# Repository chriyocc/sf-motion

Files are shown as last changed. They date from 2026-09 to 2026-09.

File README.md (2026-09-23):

# SF-Motion

**Open-source BLDC/PMSM motor control platform based on STM32 and Field-Oriented Control (FOC).**

The project includes:

- FOC firmware
- Custom motor driver hardware
- KiCad schematic and PCB design
- Gerber and BOM files
- Python communication and control tools
- PyQt/PyQtGraph GUI for motor monitoring and testing

> ⚠️ This project is under active development. Hardware and firmware may change between versions.

## My Tips
For everyday operation, calibration, control modes, plotting, and troubleshooting, see the [complete motor user guide](MOTOR_USER_GUIDE.md).

To start virtual env
`Set-ExecutionPolicy -Scope Process -ExecutionPolicy Bypass`
`.venv\Scripts\Activate.ps1`

To start GUI
`python communication/motor.py`

## Hardware Prerequisites

You will need:
- FOC Driver Board
- ST-Link programmer/debugger with 3-pin Molex pico-blade P1.25mm connector
- DC power supply
- BLDC/PMSM motor
- diametrical magnet
- USB type-C cable
- power cable with XT-30 female connector

The hardware design is available in:
```
Hardware/
├── production/        # Gerber manufacturing files
├── .kicad_sch         # Schematic
├── .kicad_pcb         # PCB design
└── ...
```

## Software Prerequisites

### 1. STM32CubeMX

Used to configure the STM32 peripherals and generate the initial project configuration.

Download: https://www.st.com/en/development-tools/stm32cubemx.html

### 2. Visual Studio Code

Used as the main development environment.

Download: https://code.visualstudio.com/

### 3. PlatformIO

PlatformIO is used to build and upload the firmware.

Install PlatformIO through the VS Code extension:
1. Open VS Code.
2. Open Extensions.
3. Search for PlatformIO IDE.
4. Install the extension.
5. Restart VS Code if required.

Verify the installation:
``` bash
pio --version
```

If `pio` is not recognized in the terminal, use the PlatformIO terminal inside VS Code or add the PlatformIO CLI directory to your system PATH.

### 4. Python

Python is required for the communication tools and GUI.

Recommended version:
```text
Python 3.10+
```

Download: https://www.python.org/downloads/

Check the installation:
``` bash
python --version
```

Create a virtual environment (recommended):
``` bash
python -m venv .venv
```

Activate it on Windows:
``` bash
.venv\Scripts\activate
```

Activate it on Linux/macOS:
``` bash
source .venv/bin/activate
```

Install the required packages:
``` bash
pip install numpy pyserial PyQt5 pyqtgraph keyboard
```

## Getting Started

Clone the repository using Git:
``` bash
git clone https://github.com/sirojudinMunir/sf-motion.git
```

Enter the project directory:
``` bash
cd SF-Motion
```

## Building the Firmware

Open the project in VS Code with PlatformIO installed.

Build the firmware:
``` bash
pio run
```

If the build is successful, the firmware binary will be generated by PlatformIO.

## Upload Firmware

Connect the ST-Link to the FOC Driver board using the 3-pin PicoBlade connector.

The board can be powered from a **6–24 V external power supply**. For the initial test, it is recommended to use **USB Type-C** as the power source if applicable.

Upload the firmware:
``` bash
pio run -t upload
```

You can also use the Upload button in the PlatformIO interface in VS Code.

## For the first test

After uploading the firmware, follow these steps:

1. Make sure the D3 LED is blinking after the firmware starts.
2. Connect the BLDC/PMSM motor wires to the FOC Driver board. Make sure the diametrical magnet is securely mounted on the motor shaft and properly aligned with the magnetic encoder on the FOC Driver board. The board should be positioned directly beneath the magnet.
3. If you are using an external power supply, set the current limit to 1 A for the initial test. This helps prevent damage if there is an unexpected issue with the board or motor.
4. Connect the USB Type-C cable to the board.
5. Run the Python motor control program:
    ```python
    python communication/motor.py
    ```
6. Select the correct COM port and click Connect.

7. Before running the motor, set the correct motor pole pairs:
    ``` python
    motor.set_pole_pairs(<your_motor_pole_pairs>)
    ```
    Replace <your_motor_pole_pairs> with the actual number of pole pairs of your motor.
8. Run the self-commissioning process:
    ``` python
    motor.self_commissioning()
    ```
    The self-commissioning process measures the motor resistance and inductance and calibrates the magnetic encoder.
    >Important: During encoder calibration, make sure the motor rotates counter-clockwise (CCW). If the motor rotates in the opposite direction, swap any two motor wires to reverse the rotation.
    Automatic motor direction detection will be implemented in a future version.
9. Save configuration
    ``` python
    motor.save_config()
    ```
10. Test the FOC motor modes using:
    ``` python
    motor.set_foc_motor_mode(<mode>)
    ```
    Available modes:

    0 -> for current control mode  
    1 -> for speed control mode  
    2 -> for position control mode  
    5 -> for open-loop mode  
    6 -> for disable the motor

> ⚠️ Keep the power supply current limit low during the first test. Do not increase the voltage or current limit until the board, encoder, and motor are confirmed to be working correctly.

---

## Support SF-Motion

If you find this project useful and would like to support its development,
you can become a sponsor:



Your support helps fund hardware development, testing, documentation,
and future improvements to SF-Motion.

## Update Needed
- Implement overcurrent protection (send fault through CAN)
- 

## Updates compared with the earlier version (2026-09-23)

This section records the firmware, custom GUI, and communication fixes made after the PID/control review. The comparison is against the code before those fixes, rather than a tagged release.

### Firmware changes

| Area | Earlier behavior | Updated behavior |
| --- | --- | --- |
| Saved position PID cutoff | Startup replaced the saved derivative filter cutoff with 20 Hz. | Startup preserves the saved cutoff and recalculates its coefficient after setting the sampling period. |
| PI/PID anti-windup | The integral could keep growing when the proportional term, or combined P+D term, already exceeded the output limit. | Integration stops when it would drive the output further into saturation, while allowing the integral to unwind. |
| PID validation and acknowledgements | Negative gains could be ignored while returning success; negative output maxima could invert the bounds. | PID setters reject invalid values and return an error through the communication protocol. Validation includes non-finite values, ordered output bounds, nonnegative gains/deadbands, and positive filter cutoff and sampling period. |
| PID reset | Reset cleared the integral and previous error but retained filtered derivative history. | Reset also clears the filtered derivative history. |
| USB transmit buffer | A new frame could overwrite bytes still being used by an outstanding USB transfer. | CDC checks availability, then copies the frame into its own transmit buffer before starting the transfer. Oversized frames are rejected. |

### Custom GUI and Python communication changes

These control changes apply to `communication/plotter_custom.py`; the shared protocol changes are in `communication/SFMotionCom.py` and `communication/MotorProtocol.py`.

| Area | Earlier behavior | Updated behavior |
| --- | --- | --- |
| Disable command | A timeout while sending a zero current/speed setpoint could prevent the disable command from being sent. | The GUI attempts disable even when the preliminary zero fails. An unconfirmed disable is reported as unconfirmed. |
| Relative position moves | Targets used the last plotted angle, which became stale when plotting was paused. | The GUI reads the angle directly from the board before calculating a relative target. A failed or non-finite read cancels the move. The position demo also reads its starting angle directly. |
| Reconnect and Apply All | Previously loaded parameters remained eligible for Apply All after reconnecting. | Reconnect, disconnect, a failed Read All, or a failed Apply All invalidates the loaded-parameter state. A successful Read All is required before Apply All is allowed again. |
| PID input fields | PID fields allowed negative values regardless of their meaning. | Gains, deadbands, and output maxima are nonnegative; derivative cutoff is positive; field-weakening output minimum is nonpositive. The protocol validates all values in a PID group before its first write. |
| Request/reply handling | Requests consumed the next queued reply, allowing delayed replies to disrupt later requests. | Requests are serialized. A timeout, transport failure, or malformed/mismatched reply invalidates the session and requires reconnecting. A disable write remains possible, but is explicitly unconfirmed in that state. |
| Partial parameter updates | Failure during a group write could leave some registers updated without a clear recovery instruction. | Failures explicitly report a possible partial update and instruct the user to reconnect if required, then read parameters before retrying. |
| Connection setup failures | Only serial-specific exceptions were caught during connection setup. | Setup failures also clean up the connection and report the error. |

### Applying the update

- **Firmware changes require a successful flash and verification.** Building alone does not update the board.
- Build the main firmware with `pio run -e genericSTM32F405RG`. The output is `.pio/build/genericSTM32F405RG/firmware.bin`.
- **GUI changes require restarting the Python GUI.** After connecting, use Read All Parameters before Apply All.
- PID register mappings and the on-wire frame format remain unchanged.

### Validation and remaining limitations

- The main firmware build passed.
- All 16 Python GUI/protocol tests passed, including the two existing plotting tests and 14 new regression tests. Serial interactions in these tests are mocked.
- Added C regression tests for PI/PID saturation and unwinding, invalid values, filter initialization, and reset behavior. They were compiled with the ARM toolchain but have not been executed here.
- PID groups still use separate register writes; they are **not atomic**. A connection failure can leave a partial update, and automatic rollback is not attempted.
- Motor behavior and USB transfer behavior have not been verified on hardware. The reported CubeProgrammer erase failure remains unresolved; the updated firmware has not been confirmed installed on the board.
- The VCAP capacitor values discussed during troubleshooting are a hardware check, not a hardware modification included in this update.

See [hardware-free test instructions and communication recovery](tests/README.md) for details.

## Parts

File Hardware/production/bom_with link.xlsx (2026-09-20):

Designator | Footprint | Quantity | Value | LCSC Part # | Link
C1, C10, C11, C2, C21, C3, C31, C37, C4, C40, C41, C45, C47, C48, C49, C5, C50, C51, C7 | 0402 | 19 | 100nF | C1525 | https://item.taobao.com/item.htm?id=619644090710
C12, C16, C17, C25, C26, C27, C28, C29, C30, C32, C33, C34, C35, C38, C39, C43, C44 | 0805 | 17 | 10uF | C22367830 | https://item.taobao.com/item.htm?id=537776958252
C13, C15 | 0603 | 2 | 0.1uF | C1591 | https://item.taobao.com/item.htm?id=537669338432&skuId=5720849848357
C14 | 0805 | 1 | 4.7uF | C98192 | https://item.taobao.com/item.htm?id=522572786930
C18, C20, C22 | 0603 | 3 | 1uF | C5199872 | https://item.taobao.com/item.htm?id=537669338432&skuId=5720849848378
C19 | 0603 | 1 | 47nF | C1622 | https://item.taobao.com/item.htm?id=537669338432&skuId=5720849848289
C23 | 0603 | 1 | 2.2uF | C23630 | https://item.taobao.com/item.htm?id=537669338432&skuId=5720849848299
C24 | 0402 | 1 | 10nF | C15195 | https://item.taobao.com/item.htm?id=523808399191&skuId=5896917567579
C36, C42, C46 | 0402 | 3 | 1nF | C14442 | https://item.taobao.com/item.htm?id=523808399191&skuId=5896917567577
C6 | 0402 | 1 | 1uF | C29266 | https://item.taobao.com/item.htm?id=523832610965
C8, C9 | 0402 | 2 | 33pF | C70465 | https://item.taobao.com/item.htm?id=574673920044&skuId=5723010237031
D1, D2 | 0603 | 2 | LED RED | C19171390 | https://item.taobao.com/item.htm?id=607210300413
D3 | 0603 | 1 | LED GREEN | C2986048 | https://item.taobao.com/item.htm?id=522573309525
D4, D5 | D_SOD-123 | 2 | MBR0530 | C5204746 | https://item.taobao.com/item.htm?id=685355899371
FB1 | 0603 | 1 | fcm 1608-0603 | C19330 | https://item.taobao.com/item.htm?id=522576784852&skuId=5903685374892
J1, J8, J9 | Molex_PicoBlade_53261-0371_1x03-1MP_P1.25mm_Horizontal | 3 | Conn_01x03_MountingPin | C293630 | https://item.taobao.com/item.htm?id=528734911747&skuId=4981522281626
J10 | Molex_PicoBlade_53261-0671_1x06-1MP_P1.25mm_Horizontal | 1 | Conn_01x06_MountingPin | C17393620 | https://item.taobao.com/item.htm?id=528734911747&skuId=4981522281629
J11 | Molex_PicoBlade_53261-0571_1x05-1MP_P1.25mm_Horizontal | 1 | Conn_01x05_MountingPin | C17256390 | https://item.taobao.com/item.htm?id=528734911747&skuId=4981522281628
J2, J3 | AMASS_XT30PW-M_1x02_P2.50mm_Horizontal | 2 | Conn_01x02 | C431092 | https://item.taobao.com/item.htm?id=635227665423&skuId=4544457080562
J4, J5, J6 | SolderWire-0.25sqmm_1x01_D0.65mm_OD2mm | 3 | Conn_01x01
J7 | USB_C_Receptacle_G-Switch_GT-USB-7010ASV | 1 | USB_C_Receptacle_USB2.0_16P | C2927039 | https://item.taobao.com/item.htm?id=573090887123&skuId=5770750381254
L1 | L_SMD_4X4 | 1 | 22uH | C6364792 | https://item.taobao.com/item.htm?id=589062675723
Q1, Q2, Q3, Q4, Q5, Q6 | TDSON-8-1 | 6 | WSD30100DN56 | C2862136 | https://item.taobao.com/item.htm?id=663046959853
R1, R3 | 0402 | 2 | 10k | C60490 | https://item.taobao.com/item.htm?id=523791322923
R10, R11, R7, R8 | 0402 | 4 | R | Use 75k for R8,R11 | https://item.taobao.com/item.htm?id=525634101247
R12, R15, R17, R21, R22, R25 | 0603 | 6 | 10R | C844919 | https://item.taobao.com/item.htm?id=525741229141&skuId=5869898526190
R13, R19, R23 | R_Shunt_Ohmite_LVK20 | 3 | 0.01R | C844898
R14, R2, R20, R24, R32, R33, R34, R4, R5 | 0402 | 9 | 1k | C852624 | https://item.taobao.com/item.htm?id=559832085134&skuId=5881534858898
R16 | 0603 | 1 | 39k | C163424 | https://item.taobao.com/item.htm?id=525898564027
R18 | 0603 | 1 | 2k2 | C125931 | https://item.taobao.com/item.htm?id=525826728150
R26 | 0402 | 1 | 1k8 | C163481 | https://item.taobao.com/item.htm?id=632063701563
R27, R28 | 0402 | 2 | 100R | C705627 | https://item.taobao.com/item.htm?id=559832085134&skuId=5881534858893
R29, R31 | 0402 | 2 | 30R | C852718 | https://item.taobao.com/item.htm?id=631379668328&skuId=5880747587790
R30 | 0603 | 1 | 120R | C125925 | https://item.taobao.com/item.htm?id=525596814299
R35, R36, R37 | 0402 | 3 | 2k | C852711 | https://item.taobao.com/item.htm?id=631736632107&skuId=5878925082880
R6 | 0603 | 1 | 18k | C309650 | https://item.taobao.com/item.htm?id=559889370450
R9 | 0603 | 1 | 3k3 | C144661 | https://item.taobao.com/item.htm?id=525777943950&skuId=5869585235017
TP1, TP2, TP3, TP4, TP5, TP6, TP7 | TestPoint_Pad_D1.0mm | 7 | TestPoint
U1 | LQFP-64_10x10mm_P0.5mm | 1 | STM32F405RGTx | C15742 | https://item.taobao.com/item.htm?id=522577756409
U10 | TSSOP-14_4.4x5mm_P0.65mm | 1 | AS5047D | C2693743 | https://item.taobao.com/item.htm?id=1029683823182
U2 | QFN50P700X700X100-49N | 1 | DRV8323RHRGZR | C543035 | https://item.taobao.com/item.htm?id=973872188161&from=cart&skuId=6093104858737&upStreamPrice=1350
U3 | SOT-23-5 | 1 | LP2985-3.3 | C95414 | https://item.taobao.com/item.htm?id=572237742889
U4, U6, U7 | TSSOP-8_4.4x3mm_P0.65mm | 3 | INA240A1PW | C93965 | https://item.taobao.com/item.htm?id=756730260979
U5 | SOT-23-5 | 1 | LM321 | C5252901 | https://item.taobao.com/item.htm?id=666849623425
U8 | SOT-23-6 | 1 | USBLC6-2SC6 | C2827654 | https://item.taobao.com/item.htm?id=763430084934
U9 | HVSON-8-1EP_3x3mm_P0.65mm_EP1.6x2.4mm | 1 | TJA1051TK-3 | C2875699 | https://item.taobao.com/item.htm?id=736463710815
Y1 | Crystal_SMD_3225-4Pin_3.2x2.5mm | 1 | 12MHz | C9002 | https://item.taobao.com/item.htm?id=534883366755&skuId=5909761239845

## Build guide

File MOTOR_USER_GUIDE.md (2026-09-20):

# SF-Motion Motor and Plotter User Guide

Checked against this workspace's Python API and firmware on 2026-09-20.
This guide assumes the firmware flashed on your board matches this project.
Examples use your 7-pole-pair motor and sensored FOC. Current and speed examples
are small starting commands, not universal safe limits for every motor or load.

## Contents

1. [Everyday quick start](#1-everyday-quick-start)
2. [Launch and connect](#2-launch-and-connect)
3. [First-time commissioning](#3-first-time-commissioning)
4. [Modes and units](#4-modes-and-units)
5. [Current control](#5-current-control)
6. [Speed control](#6-speed-control)
7. [Position control](#7-position-control)
8. [Encoder readings](#8-encoder-readings)
9. [Plot controls](#9-plot-controls)
10. [PID settings](#10-pid-settings)
11. [Save, reopen, and reset](#11-save-reopen-and-reset)
12. [Troubleshooting](#12-troubleshooting)
13. [Complete command reference](#13-complete-command-reference)
14. [HSI clock notes](#14-hsi-clock-notes)
15. [Implementation references](#15-implementation-references)

## 1. Everyday quick start

Use this after successful commissioning and saving the configuration.
Enter Python commands in the app's bottom console, one line at a time.
Do not type the `>>>` prompt. Use normal underscores, without backslashes.

Connect the app, then start from disabled sensored operation:

```python
motor.set_foc_motor_mode(6)
motor.set_foc_mode(0)
motor.get_pole_pairs()
```

Choose ONE control mode:

| Task | Select mode first | Then send target |
| --- | --- | --- |
| Current/torque | `motor.set_foc_motor_mode(0)` | `motor.set_foc_current_set_point(0.05)` |
| Speed | `motor.set_foc_motor_mode(1)` | `motor.set_foc_speed_set_point(50)` |
| Position | `motor.set_foc_motor_mode(2)` | Follow the relative-angle example in section 7 |
| Disable drive | `motor.set_foc_motor_mode(6)` | No target needed |

The firmware ignores a current, speed, or position setpoint when its matching
motor mode is not active. It can still reply with `{'err_code': 0}`.

Before disconnecting or closing the app:

```python
motor.set_foc_motor_mode(6)
```

Disable removes commanded drive; it is not a controlled braking command or a
guarantee that a moving shaft stops instantly. The current app does not send
disable when you close it or disconnect USB. Keep the DC supply cutoff accessible.

## 2. Launch and connect

Run this in PowerShell from the project folder if `.venv` already exists:

```powershell
.\.venv\Scripts\python.exe communication\motor.py
```

For a fresh Python environment, run these once:

```powershell
python -m venv .venv
.\.venv\Scripts\python.exe -m pip install numpy pyserial PyQt5 pyqtgraph keyboard
.\.venv\Scripts\python.exe communication\motor.py
```

1. Connect USB-C with a data-capable cable.
2. Click **Connect**, select the board's COM port, and use the default 115200 baud.
3. Check communication in the app console:

```python
motor.get_foc_motor_mode()
motor.get_foc_mode()
motor.get_pole_pairs()
```

USB communication alone does not establish that the motor power stage is powered.
For motor movement and commissioning, connect the proper DC bus supply and all
three motor phases. Use the voltage appropriate to your board and motor, with a
conservative supply current limit. Secure the motor and leave its shaft clear.
Disconnect power before changing phase wiring.

Response meanings:

| Response | Meaning |
| --- | --- |
| `{'err_code': 0}` | Handler reported success; not proof of motion, valid calibration, or correct mode |
| `{'err_code': 255}` | Firmware's signed `-1` error decoded as unsigned by Python |
| `{'value': 2.5}` | A measured value or setting; units depend on the command |
| `{'mode': 2}` | A mode value; use the correct mode table below |
| Timeout/traceback | Communication did not complete; do not assume the command had no effect |

## 3. First-time commissioning

Do this for a new motor/encoder setup, changed phase wiring or magnet alignment,
lost calibration, or a previous attempt made with disconnected phases.
You do not need to repeat it just because you reopen the app.

### Prepare

Connect the phases, mount the encoder magnet correctly, power the DC bus, and
allow the motor to rotate freely during encoder calibration.

```python
motor.set_foc_motor_mode(6)
motor.set_foc_mode(0)
motor.set_pole_pairs(7)
motor.get_pole_pairs()
```

Seven pole pairs means 14 magnetic poles. Do not use 7 for a different motor
unless that is its actual pole-pair count.

### Run

```python
motor.self_commissioning()
```

This Python helper starts resistance, d-axis inductance, and q-axis inductance
measurements with one-second delays, prints their values, calculates current PI
gains using a 500 Hz bandwidth, and starts encoder calibration.

**The helper returns after starting encoder calibration. It does not wait for
encoder calibration to finish and does not save the configuration.** Allow the
complete calibration movement to finish before changing modes or saving. There
is no exposed calibration-complete query in the current command API. A stopped
shaft alone is not proof of successful calibration if it stalled or never moved.

The project README requires CCW rotation during encoder calibration. Confirm the
viewing convention and encoder direction for your assembly. If phase order must
change, switch off power before swapping two phases, then recommission.

### Inspect, then save

After calibration has completed:

```python
motor.get_motor_param()
motor.get_pid_id()
motor.get_pid_iq()
motor.set_foc_motor_mode(6)
motor.save_config()
```

The earlier readings around `Rs = 594` and `Rs = 1945` obtained with disconnected
motor wires were not valid motor measurements. Do not reuse their derived PI
gains. Resistance and inductance should be finite, physically plausible for your
motor, and reasonably repeatable. The helper does not reject implausible values.

The estimator uses voltage/current for resistance and SI equations for inductance
(ohms and henries). The bandwidth helper divides the reported Rs/Ld/Lq by two
before calculating gains; do not assume an independently measured phase value
has the same convention without checking the measurement method.

## 4. Modes and units

These are TWO different settings:

### Motor control mode: what the motor regulates

```python
motor.set_foc_motor_mode(2)
motor.get_foc_motor_mode()
```

| Number | Mode | Normal use |
| --- | --- | --- |
| 0 | Torque/current | Command current in amperes |
| 1 | Speed | Command mechanical RPM |
| 2 | Position | Command accumulated angle in degrees |
| 3 | Encoder calibration enum | Use `start_calibrate_abs_encoder()` instead of selecting this directly |
| 4 | Audio | Specialized firmware functionality, not a normal motion test |
| 5 | Voltage/open-loop | Advanced direct voltage-vector testing |
| 6 | Disabled | Disable normal motor drive |

### FOC feedback mode: how rotor angle is obtained

```python
motor.set_foc_mode(0)
motor.get_foc_mode()
```

| Number | Mode |
| --- | --- |
| 0 | Sensored; use this for your encoder setup |
| 1 | Sensorless SMO/HFI |
| 2 | New sensorless SMO/HFI |
| 3 | Hybrid |

Stay with sensored mode for these instructions. Sensorless/hybrid operation needs
separate validation for the motor and operating range.

### Units you will see

| Signal | Units / meaning |
| --- | --- |
| `actual_angle`, `pos_ref` | Accumulated mechanical position in degrees; firmware applies configured gear ratio |
| `actual_rpm`, `rpm_ref` | Mechanical revolutions per minute |
| `m_angle_rad`, `m_angle_rad_comp` | Wrapped mechanical radians, approximately 0 to 6.283 |
| `e_rad` | FOC electrical angle in radians; source depends on operating mode |
| `Is_ref`, `id`, `iq`, phase currents | Amperes, subject to correct current-sense scaling |
| `v_bus` | DC bus voltage in volts, subject to correct sensing scale |

At gear ratio 1, 360 mechanical degrees is one shaft revolution. With seven pole
pairs, the electrical angle cycles seven times during one mechanical revolution.

## 5. Current control

Current mode controls torque-producing current. It does not regulate speed or
hold an angle. An unloaded motor can continue accelerating with nonzero current.
Supply current is not the same quantity as controlled motor phase/dq current.

```python
motor.set_foc_motor_mode(6)
motor.set_foc_mode(0)
motor.set_foc_motor_mode(0)
motor.set_foc_current_set_point(0.02)
motor.get_foc_current_set_point()
```

Observe the response before trying a slightly larger command:

```python
motor.set_foc_current_set_point(0.05)
```

Return to zero before testing the opposite sign:

```python
motor.set_foc_current_set_point(0)
motor.set_foc_current_set_point(-0.05)
```

Finish:

```python
motor.set_foc_current_set_point(0)
motor.set_foc_motor_mode(6)
```

Useful plots: `Is_ref`, `iq`, `id`. With field weakening and MTPA disabled,
`iq` should approximately track the signed current request and `id` should remain
near zero. Small commands may not overcome friction or sensor noise.
The speed PID output limit does not provide a general limit for direct current mode.

## 6. Speed control

```python
motor.set_foc_motor_mode(6)
motor.set_foc_mode(0)
motor.set_foc_motor_mode(1)
motor.set_foc_speed_set_point(50)
motor.get_foc_speed_set_point()
```

After verifying tracking, change speed:

```python
motor.set_foc_speed_set_point(100)
```

To reverse, first command zero and wait for the shaft to slow down:

```python
motor.set_foc_speed_set_point(0)
```

Then:

```python
motor.set_foc_speed_set_point(-50)
```

Finish:

```python
motor.set_foc_speed_set_point(0)
motor.set_foc_motor_mode(6)
```

Plot `rpm_ref` and `actual_rpm` together. Zero speed can actively resist rotation
while speed mode remains enabled; disabling removes that active drive.

## 7. Position control

### Move relative to the current position

Start stationary. Enter position mode and subscribe to the degree signals:

```python
motor.set_foc_motor_mode(6)
motor.set_foc_mode(0)
motor.set_foc_motor_mode(2)
motor.plotter_add_line('actual_angle')
motor.plotter_add_line('pos_ref')
```

Let fresh samples arrive before the next commands. Make sure the graph is not
paused. Read the current angle and move forward 30 degrees:

```python
current = plotter.channels['actual_angle']['buffer'][-1]
motor.set_foc_position_set_point(current + 30)
```

The motor should approach the target, stop, and actively hold it. To move another
30 degrees, read `current` again first. A variable does not update itself.

```python
current = plotter.channels['actual_angle']['buffer'][-1]
motor.set_foc_position_set_point(current - 30)
```

Check the commanded target:

```python
motor.get_foc_position_set_point()
```

Check the tracking error after fresh samples have arrived:

```python
motor.get_foc_position_set_point()['value'] - plotter.channels['actual_angle']['buffer'][-1]
```

The result is target minus actual angle in degrees. Plot samples have latency,
so use this for slow bench tests, not synchronized motion control.

### Why `current + 180` worked while `10` looked wrong

`set_foc_position_set_point()` is an ABSOLUTE accumulated-angle command.
If `actual_angle` is 130000 degrees:

| Command target | Requested travel |
| --- | --- |
| `130030` | Forward 30 degrees |
| `130180` | Forward 180 degrees |
| `10` | Backward 129990 degrees, roughly 361 turns |

The firmware does not choose the shortest route modulo 360 degrees.
Do not send `10` to mean "move forward 10 degrees".

### Use your own session zero

While stationary, capture a reference:

```python
home = plotter.channels['actual_angle']['buffer'][-1]
motor.set_foc_position_set_point(home + 30)
```

After arrival, try another offset, then return:

```python
motor.set_foc_position_set_point(home + 90)
```

```python
motor.set_foc_position_set_point(home)
```

`home` is only a Python variable. It does not zero the encoder, persist through
app restarts, or establish physical homing. Recapture it after a board reset.
There is no exposed zero-position command in the current JSON API.

Changing INTO position mode initializes its target to the current angle. Setting
mode 2 again while already in mode 2 does not reset the target.

Release holding torque when finished:

```python
motor.set_foc_motor_mode(6)
```

## 8. Encoder readings

With the drive disabled, turn the shaft by hand and repeat:

```python
motor.set_foc_motor_mode(6)
motor.get_foc_actual_e_rad()
```

This returns the encoder-derived electrical angle in radians, not accumulated
mechanical degrees. A changing value confirms that this reading responds to
rotation; it does not by itself prove correct phase alignment or calibration.

For mechanical-angle inspection:

```python
motor.plotter_add_line('m_angle_rad')
motor.plotter_add_line('m_angle_rad_comp')
motor.plotter_add_line('e_rad')
```

The jump between approximately 6.283 and 0 is normal angle wrapping. In open-loop
mode, the plotted `e_rad` is the commanded FOC angle; the direct getter above
specifically reads `encoder_e_angle_rad`.

## 9. Plot controls

### Add, remove, list, and clear

```python
motor.plotter_add_line('actual_angle')
motor.plotter_remove_line('actual_angle')
motor.plotter_channels
```

Remove every channel known to the current Python connection:

```python
for name in list(motor.plotter_channels): motor.plotter_remove_line(name)
```

There is no implemented `motor.plotter_remove_all_line()` helper in the current
MotorProtocol class, despite a reference to it in the demo code.

Clear sample history without removing subscriptions or changing motor position:

```python
plotter.clear_data()
```

Wait for new samples before using `buffer[-1]` after clearing.

### Reset the range

Enable ongoing automatic Y scaling:

```python
plotter.auto_range_check.setChecked(True)
plotter.auto_range()
```

For wrapped radians only:

```python
plotter.auto_range_check.setChecked(False)
plotter.plot_widget.setYRange(0, 6.5)
```

For a small current test:

```python
plotter.auto_range_check.setChecked(False)
plotter.plot_widget.setYRange(-0.2, 0.2)
```

For accumulated position around the current angle:

```python
current = plotter.channels['actual_angle']['buffer'][-1]
plotter.auto_range_check.setChecked(False)
plotter.plot_widget.setYRange(current - 60, current + 60)
```

Auto Range uses all subscribed channels and their retained history. Clear old
history when a previous extreme value dominates the scale. Do not mix large
accumulated degrees with radians or small currents on the same Y axis.
The live X axis follows the sample window automatically; it is sample count,
not a calibrated time axis.

### Pause and resume

Click **Pause** to freeze the graph and **Resume** to continue, or toggle:

```python
plotter.toggle_pause()
```

This toggles the current state. Pausing the plot does NOT stop the motor.
Use live, freshly updated samples for relative position commands.

### Recommended channel sets

Remove previous channels first, then add the desired group one line at a time.

| Test | Channels |
| --- | --- |
| Current | `Is_ref`, `iq`, `id` |
| Speed | `rpm_ref`, `actual_rpm` |
| Position | `pos_ref`, `actual_angle` |
| Encoder | `m_angle_rad`, `m_angle_rad_comp`, `e_rad` |
| Supply | `v_bus` |

Firmware supports at most **10 simultaneous channels**. Exceeding this can make
the Python channel list disagree with the device even when the reply is zero.

After reconnecting to a board that stayed powered, old device subscriptions may
remain while Python starts a new list. If labels and values seem mismatched,
disable the motor, remove all known dictionary entries, then add only your desired
channels and clear history:

```python
motor.set_foc_motor_mode(6)
for name in list(motor.plotter_dict): motor.plotter_remove_line(name)
motor.plotter_add_line('actual_angle')
motor.plotter_add_line('pos_ref')
plotter.clear_data()
plotter.auto_range_check.setChecked(True)
```

### All available channels

| Group | Names |
| --- | --- |
| Phase currents | `ia`, `ib`, `ic` |
| Stationary-frame currents | `i_alpha`, `i_beta` |
| Rotating-frame currents | `id`, `iq` |
| Phase voltage fields | `va`, `vb`, `vc` |
| Stationary-frame voltage fields | `v_alpha`, `v_beta` |
| Rotating-frame voltage fields | `vd`, `vq` |
| Electrical angle | `e_rad` |
| Speed | `actual_rpm`, `rpm_ref` |
| Position | `actual_angle`, `pos_ref` |
| Current reference | `Is_ref` |
| Mechanical angle | `m_angle_rad`, `m_angle_rad_comp` |
| Supply voltage | `v_bus` |

Voltage fields are controller variables; do not assume they are independently
measured motor-terminal voltages.

## 10. PID settings

Read existing settings before changing anything:

```python
motor.get_pid_id()
motor.get_pid_iq()
motor.get_pid_speed()
motor.get_pid_position()
```

The control cascade is position -> speed reference -> current reference -> drive.

| Setting | What it controls |
| --- | --- |
| Position `out_max` | Maximum magnitude of the speed reference, in RPM |
| Speed `out_max` | Maximum magnitude of its current reference, in A |
| Position `deadband` | Position error band, in degrees |
| Speed `deadband` | Speed error band, in RPM |
| Current `deadband` | Current error band, in A |
| Position `d_fc` | Derivative low-pass filter cutoff, in Hz |

The source default position output limit is only **3 RPM**, so a long position
move can be very slow. The source default speed-controller output limit is
**10 A**, which is not an appropriate assumed limit for every bench motor.
Read your saved values; they may differ from the defaults.

Example: preserve position gains but change the speed cap to 20 RPM after
confirming that speed is appropriate for your setup. Stop/disable first:

```python
motor.set_foc_motor_mode(6)
p = motor.get_pid_position()
motor.set_pid_position(p['kp'], p['ki'], p['kd'], 20.0, p['deadband'], p['d_fc'])
motor.get_pid_position()
```

Example: preserve speed gains but set its output cap to 0.2 A, only if that current
is appropriate for your motor. This may be too little to move a loaded motor:

```python
s = motor.get_pid_speed()
motor.set_pid_speed(s['kp'], s['ki'], 0.2, s['deadband'])
motor.get_pid_speed()
```

Change one parameter at a time and retest with small commands. Increasing a cap
does not fix wrong encoder alignment, phase order, or invalid current sensing.
Do not copy arbitrary gains to cure those problems. Save only validated settings.

The helper below recalculates and writes current PI gains; it is not a getter:

```python
motor.set_foc_bandwidth(500)
```

Use it only with valid Rs/Ld/Lq measurements and a deliberately chosen bandwidth.

## 11. Save, reopen, and reset

### Save validated configuration

```python
motor.set_foc_motor_mode(6)
motor.save_config()
```

The save path copies motor mode as well as motor parameters and controller
settings into storage. Saving while disabled avoids deliberately persisting an
active mode. Encoder calibration data lives in the stored configuration as well.
Saving is not required for each motion target or plot change.

Reopening the app does not require self-commissioning if the board still has a
valid saved configuration. A board reset reloads stored configuration. Reconnect,
disable, inspect settings, and select the mode you want to use. Python variables
such as `home`, plot history, and accumulated multi-turn tracking are not a
persistent physical homing system.

### Restore defaults only intentionally

```python
motor.set_foc_motor_mode(6)
motor.set_default_config()
```

This replaces configuration in RAM with defaults, including zero motor Rs/Ld/Lq
and cleared encoder calibration storage fields. It is not a routine reconnect or
graph-reset command. Recommission before driving, then save the validated result.
Do not use it when all you need is `plotter.clear_data()`.

## 12. Troubleshooting

| Symptom | Check / action |
| --- | --- |
| Setpoint returns zero but nothing happens | Read `get_foc_motor_mode()`; select the matching mode BEFORE sending the target |
| Position slowly spins for a long time | Compare accumulated `actual_angle` with target; use a fresh `current + offset` |
| Position moves and stops, then resists movement | Expected position holding behavior |
| Position move is extremely slow | Read position PID `out_max`; default is 3 RPM |
| A 10-degree command barely moves | Check target error, current limit, friction, tuning, and plot scale before increasing commands |
| Angle looks flat near 130000 | Use a narrow Y range around current angle; do not mix degree and radian signals |
| Electrical angle jumps between 0 and 6.283 | Normal wrapped angle behavior |
| Encoder getter changes but graph does not | Resume plot, verify subscriptions/labels, and reset the range |
| `KeyError: 'actual_angle'` | Add that channel and allow fresh data to arrive |
| Empty-buffer `IndexError` | Wait for samples after adding/clearing; verify connection and Resume state |
| Plot values make no sense after reconnect | Remove all dictionary channels and re-add the desired group, as in section 9 |
| Current mode keeps accelerating | It regulates current, not speed; command zero and disable |
| Motor buzzes, jerks, or draws excessive current | Disable; inspect phase wiring, encoder alignment, commissioning, and current sensing |
| Rs/Ld/Lq are huge or change wildly | Check powered DC bus, all phases, measurement scaling, and connections; do not save invalid gains |
| No motion on USB alone | Verify the separate motor DC supply and power stage |
| USB disconnects or commands time out | Stop through the supply if needed; check power/noise, cable, clock source, and reconnect |
| Closing app leaves motor running | App disconnect is not motor disable; disable before closing |

The bundled demo methods are not recommended with this revision:
`MotorSequenceThread` calls the missing `plotter_remove_all_line()` helper;
`run_motor_current_demo()` selects speed mode; and the position demo uses absolute
targets around zero. Use the explicit manual sequences in this guide.
Avoid long loops with `time.sleep()` in the GUI console: they block the GUI thread
and prevent timely interaction with its controls.

## 13. Complete command reference

These are signatures, not a sequence to execute. Names such as `value`, `kp`, or
`idx` are placeholders. Use positional arguments in the order shown.
All commands below are called on `motor`.

### Configuration and mode commands

| Signature | Purpose |
| --- | --- |
| `set_default_config()` | Replace runtime configuration with defaults |
| `save_config()` | Persist current configuration; disable first |
| `set_foc_mode(mode)` / `get_foc_mode()` | Select/read feedback strategy |
| `set_foc_motor_mode(mode)` / `get_foc_motor_mode()` | Select/read control mode |
| `set_pole_pairs(value)` / `get_pole_pairs()` | Motor pole-pair count |
| `set_kv(value)` / `get_kv()` | Motor KV parameter |
| `set_rs(value)` / `get_rs()` | Resistance parameter |
| `set_ld(value)` / `get_ld()` | d-axis inductance parameter |
| `set_lq(value)` / `get_lq()` | q-axis inductance parameter |
| `set_flux_linkage(value)` / `get_flux_linkage()` | Flux-linkage parameter |

Manual electrical-parameter setters are advanced overrides. Do not enter guessed
values or interchange millihenries and henries.

### Controllers

| Signature | Purpose |
| --- | --- |
| `set_pid_id(kp, ki, deadband)` / `get_pid_id()` | d-axis current PI |
| `set_pid_iq(kp, ki, deadband)` / `get_pid_iq()` | q-axis current PI |
| `set_pid_speed(kp, ki, out_max, deadband)` / `get_pid_speed()` | Speed PI; output cap in A |
| `set_pid_position(kp, ki, kd, out_max, deadband, d_fc)` / `get_pid_position()` | Position PID; output cap in RPM |
| `set_field_weakening(kp, ki, out_min)` / `get_field_weakening()` | Advanced field-weakening controller |
| `set_field_weakening_enable(enable)` / `get_field_weakening_enable()` | 0 disables, 1 enables field weakening |
| `set_mtpa_enable(enable)` / `get_mtpa_enable()` | 0 disables, 1 enables maximum-torque-per-ampere logic |

Field weakening and MTPA default to disabled. Leave them disabled for the basic
tests; they require validated motor parameters and operating limits.

### Targets and feedback

| Signature | Purpose |
| --- | --- |
| `set_foc_current_set_point(value)` / `get_foc_current_set_point()` | Current target in A; setter requires motor mode 0 |
| `set_foc_speed_set_point(value)` / `get_foc_speed_set_point()` | Speed target in RPM; setter requires motor mode 1 |
| `set_foc_position_set_point(value)` / `get_foc_position_set_point()` | Absolute accumulated-degree target; setter requires motor mode 2 |
| `get_foc_actual_e_rad()` | Encoder electrical angle in radians |
| `set_svpwm(vd, vq, e_rad)` / `get_svpwm()` | Direct voltage-vector fields; setter requires motor mode 5 |

Setpoint getters read the target, not actual motion. Use plot channels for actual
speed, accumulated position, and current. There are no corresponding direct
actual-speed/actual-position getters in this JSON API.
`set_svpwm()` specifies voltage and electrical angle, not RPM. Direct voltage can
produce large current at standstill; it is not needed for normal closed-loop use.

### Measurement and plotting

| Signature | Purpose |
| --- | --- |
| `start_measure_motor_Rs()` | Start resistance measurement |
| `start_measure_motor_Ld()` | Start d-axis inductance measurement |
| `start_measure_motor_Lq()` | Start q-axis inductance measurement |
| `start_calibrate_abs_encoder()` | Start encoder calibration motion |
| `get_abs_encoder_error_comp(idx)` | Read encoder correction table entry; use an index within the firmware LUT size |
| `plotter_add_line('name')` | Subscribe to a channel |
| `plotter_remove_line('name')` | Unsubscribe from a channel |

Measurement start commands return before the physical process finishes. Do not
launch overlapping measurements. Use the commissioning workflow unless diagnosing
the individual stages deliberately.

### Python convenience helpers

| Signature | Purpose |
| --- | --- |
| `self_commissioning()` | Measure parameters, calculate current gains, start encoder calibration |
| `get_motor_param()` | Print pole pairs, Rs, Ld, Lq |
| `set_foc_bandwidth(bw=100)` | Recalculate and write current PI gains; bandwidth in Hz |

Discover available names and argument metadata in the console:

```python
sorted(motor.commands)
motor.commands['set_pid_position']
sorted(motor.plotter_dict)
```

## 14. HSI clock notes

Your current `SystemClock_Config()` explicitly selects HSI and PLL settings
M=8, N=168, P=2, Q=7. From nominal 16 MHz HSI, these produce nominal 168 MHz system
clock and 48 MHz USB clock. The configuration is intentional, not simply an HSE
12 MHz setup running unchanged on HSI.

Nominal frequency does not guarantee clock accuracy. HSI accuracy varies with
device and operating conditions; the PLL carries that reference error into its
outputs. That can affect communication timing and real-time speed estimates.
An encoder position reading does not simply acquire the same percentage error
as the clock, because it is derived from measured angle.

For dependable USB operation, use a correctly specified external clock solution
and matching firmware configuration. Bench success with HSI does not establish
operation across temperature and supply variation. Check CAN timing margins too
before using the board on a network.

Reference: [ST RM0090 reference manual, clock-control and USB sections](https://www.st.com/resource/en/reference_manual/dm00031020-stm32f405-407-415-417-437-455-469-application-note-stmicroelectronics.pdf).

## 15. Implementation references

- [Command names, arguments, and plot dictionary](communication/motor_commands.json)
- [Python protocol and commissioning helper](communication/MotorProtocol.py)
- [Plot controls and connection behavior](communication/plotter.py)
- [FOC modes and data structures](lib/FOC/FOC_utils.h)
- [Setpoint guards, mode transitions, and control cascade](lib/FOC/FOC_utils.c)
- [Firmware command handlers and plotted fields](lib/COM/com.c)
- [Saved configuration and defaults](lib/STORAGE/storage.c)
- [Measurement and encoder-calibration implementation](lib/SELF_COMMISSIONING/self_commissioning.c)
- [Board initialization and HSI clock configuration](src/Core/Src/main.c)

This guide was checked against source; its motion examples were not executed on
your physical hardware during documentation generation.

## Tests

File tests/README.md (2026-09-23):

# Hardware-free control checks

Run the Python GUI/protocol tests from the repository root:

```sh
python -B -m unittest discover -s communication/tests -v
```

They use mocked serial connections and offscreen Qt. No board is needed.

With a native C compiler, run the PID saturation, validation, and filter tests:

```sh
cc -O3 -ffast-math -Ilib/PID tests/test_pid.c lib/PID/pid_utils.c -o test_pid
./test_pid
```

The fast-math option matches the firmware's floating-point optimization assumptions.
Do not define `NDEBUG`: these tests use assertions.

Build the firmware without uploading:

```sh
pio run -e genericSTM32F405RG
```

## Communication recovery

A timeout, transport exception, or malformed/mismatched response invalidates the
client session. Reconnect before making further requests, then read all parameters.
The protocol has no transaction IDs, so a late reply to the same register cannot
be distinguished from a new reply. A disable write is still allowed in an invalid
session, but is reported as unconfirmed rather than treating a stale reply as success.

PID groups remain separate register writes. All values are validated before the
first write, but a communication failure can still leave a partial update. Such
failures are reported explicitly; Apply All requires a fresh successful Read All
after a failed apply, failed refresh, or reconnect. No automatic rollback is attempted
over a connection whose state is uncertain.

Relative position commands read current feedback directly before calculating the
target; paused plotting no longer determines the command's starting angle.

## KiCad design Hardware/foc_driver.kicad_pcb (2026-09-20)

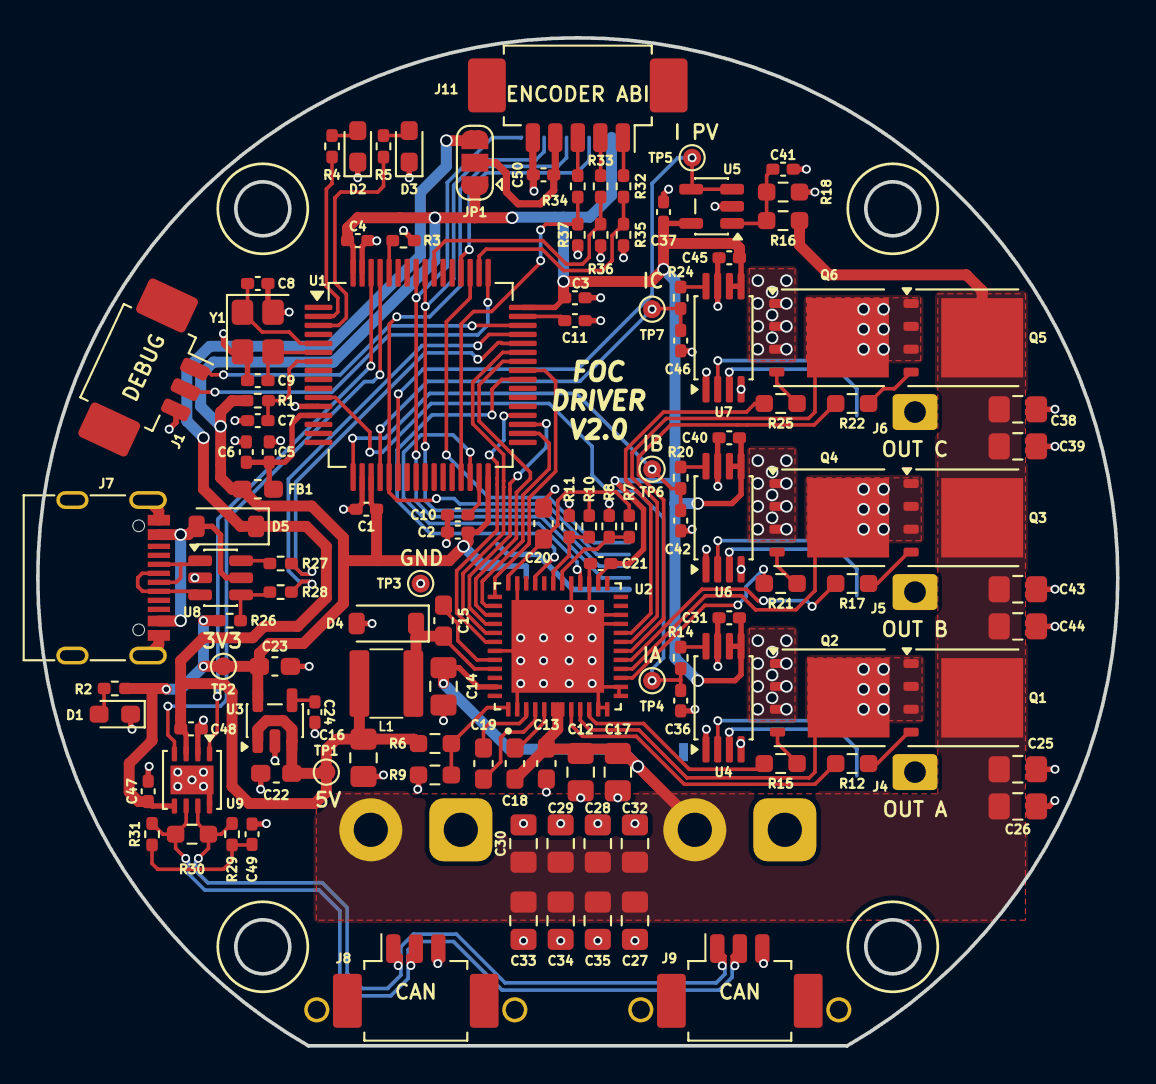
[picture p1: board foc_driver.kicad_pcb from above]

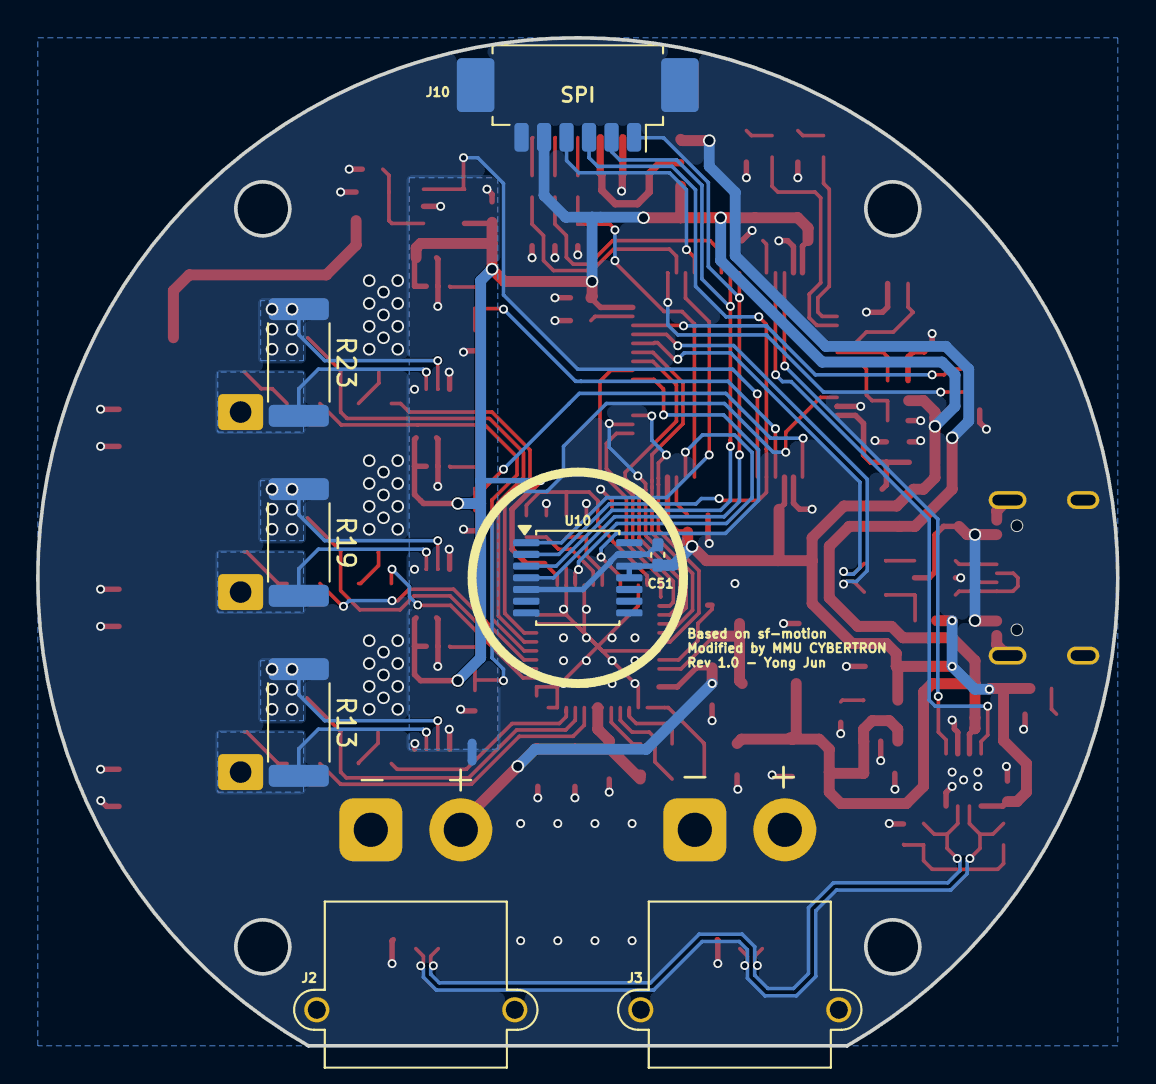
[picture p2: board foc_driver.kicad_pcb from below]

Board: 2 copper layers, 60.0 x 56.0 mm, 132 parts (9 on the bottom side), 87 nets.

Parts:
C1, C2, C3, C4, C5, C7, C10, C11, C21, C31, C37, C40, C41, C45, C47, C48, C49, C50, C51: 100nF; C_0402_1005Metric_Pad0.74x0.62mm_HandSolder
C6: 1uF; C_0402_1005Metric_Pad0.74x0.62mm_HandSolder
C8, C9: 33pF; C_0402_1005Metric_Pad0.74x0.62mm_HandSolder
C12, C16, C17, C25, C26, C27, C28, C29, C30, C32, C33, C34, C35, C38, C39, C43, C44: 10uF; C_0805_2012Metric_Pad1.18x1.45mm_HandSolder
C13, C15: 0.1uF; C_0603_1608Metric_Pad1.08x0.95mm_HandSolder
C14: 4.7uF; C_0805_2012Metric_Pad1.18x1.45mm_HandSolder
C18, C20, C22: 1uF; C_0603_1608Metric_Pad1.08x0.95mm_HandSolder
C19: 47nF; C_0603_1608Metric_Pad1.08x0.95mm_HandSolder
C23: 2.2uF; C_0603_1608Metric_Pad1.08x0.95mm_HandSolder
C24: 10nF; C_0402_1005Metric_Pad0.74x0.62mm_HandSolder
C36, C42, C46: 1nF; C_0402_1005Metric_Pad0.74x0.62mm_HandSolder
D1, D2: LED RED; LED_0603_1608Metric_Pad1.05x0.95mm_HandSolder
D3: LED GREEN; LED_0603_1608Metric_Pad1.05x0.95mm_HandSolder
D4, D5: MBR0530; D_SOD-123
FB1: fcm 1608-0603; L_0603_1608Metric_Pad1.05x0.95mm_HandSolder
J1, J8, J9: Conn_01x03_MountingPin; Molex_PicoBlade_53261-0371_1x03-1MP_P1.25mm_Horizontal
J2, J3: Conn_01x02; AMASS_XT30PW-M_1x02_P2.50mm_Horizontal
J4, J5, J6: Conn_01x01; SolderWire-0.25sqmm_1x01_D0.65mm_OD2mm
J7: USB_C_Receptacle_USB2.0_16P; USB_C_Receptacle_G-Switch_GT-USB-7010ASV
J10: Conn_01x06_MountingPin; Molex_PicoBlade_53261-0671_1x06-1MP_P1.25mm_Horizontal
J11: Conn_01x05_MountingPin; Molex_PicoBlade_53261-0571_1x05-1MP_P1.25mm_Horizontal
JP1: SolderJumper_3_Open; SolderJumper-3_P1.3mm_Open_RoundedPad1.0x1.5mm
L1: 22uH; L_SMD_4X4
NT1: NetTie_2; NetTie-2_SMD_Pad0.5mm
Q1, Q2, Q3, Q4, Q5, Q6: WSD30100DN56; TDSON-8-1
R1, R3: 10k; R_0402_1005Metric_Pad0.72x0.64mm_HandSolder
R2, R4, R5, R14, R20, R24, R32, R33, R34: 1k; R_0402_1005Metric_Pad0.72x0.64mm_HandSolder
R6: 18k; R_0603_1608Metric_Pad0.98x0.95mm_HandSolder
R7, R8, R10, R11: R; R_0402_1005Metric_Pad0.72x0.64mm_HandSolder
R9: 3k3; R_0603_1608Metric_Pad0.98x0.95mm_HandSolder
R12, R15, R17, R21, R22, R25: 10R; R_0603_1608Metric_Pad0.98x0.95mm_HandSolder
R13, R19, R23: 0.01R; R_2512_6332Metric
R16: 39k; R_0603_1608Metric_Pad0.98x0.95mm_HandSolder
R18: 2k2; R_0603_1608Metric_Pad0.98x0.95mm_HandSolder
R26: 1k8; R_0402_1005Metric_Pad0.72x0.64mm_HandSolder
R27, R28: 100R; R_0402_1005Metric_Pad0.72x0.64mm_HandSolder
R29, R31: 30R; R_0402_1005Metric_Pad0.72x0.64mm_HandSolder
R30: 120R; R_0603_1608Metric_Pad0.98x0.95mm_HandSolder
R35, R36, R37: 2k; R_0402_1005Metric_Pad0.72x0.64mm_HandSolder
TP1, TP2, TP3, TP4, TP5, TP6, TP7: TestPoint; TestPoint_Pad_D1.0mm
U1: STM32F405RGTx; LQFP-64_10x10mm_P0.5mm
U2: DRV8323RHRGZR; QFN50P700X700X100-49N
U3: LP2985-3.3; SOT-23-5
U4, U6, U7: INA240A1PW; TSSOP-8_4.4x3mm_P0.65mm
U5: LM321; SOT-23-5
U8: USBLC6-2SC6; SOT-23-6
U9: TJA1051TK-3; HVSON-8-1EP_3x3mm_P0.65mm_EP1.6x2.4mm
U10: AS5047D; TSSOP-14_4.4x5mm_P0.65mm
Y1: 12MHz; Crystal_SMD_3225-4Pin_3.2x2.5mm

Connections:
+3V3: C1.1, C2.1, C3.1, C4.1, C21.2, C23.1, C31.1, C37.1, C40.1, C45.1, C47.2, C51.1, FB1.2, J10.5, JP1.1 (A), R1.1, R2.1, R26.1, TP2.1 (1_1), U1.19 (VDD), U1.32 (VDD), U1.48 (VDD), U1.64 (VDD), U2.26 (VREF), U3.5 (VOUT), U4.5 (V+), U4.6 (REF2), U5.5 (V+), U6.5 (V+), U6.6 (REF2), U7.5 (V+), U7.6 (REF2), U9.5 (VIO), U10.11 (VDD), U10.12 (VDD3V3)
+3V3A: C5.1, C6.1, FB1.1, U1.13 (VDDA)
+5V: C16.1, C22.1, C48.2, D5.1 (K), JP1.3 (B), L1.2, R6.1, TP1.1 (1_1), U3.1 (VIN), U3.3 (ON/~OFF), U9.3 (VCC)
/Communications/CAN_N: J8.2, J9.2, R30.2, R31.2, U9.6 (CANL)
/Communications/CAN_P: J8.1, J9.1, R29.2, R30.1, U9.7 (CANH)
/Communications/CAN_RX: U1.61 (PB8), U9.4 (RXD)
/Communications/CAN_TX: U1.62 (PB9), U9.1 (TXD)
/Communications/USB_N: R27.2, U1.44 (PA11)
/Communications/USB_P: R28.2, U1.45 (PA12)
/Communications/VBUS: D5.2 (A), J7.A4 (VBUS), J7.A9 (VBUS), J7.B4 (VBUS), J7.B9 (VBUS), U8.5 (VBUS)
/Encoders/CS0: U1.51 (PC10), U10.1 (~CS)
/Encoders/CS1: J10.4, U1.52 (PC11)
/Encoders/EXT_ENCDA: R32.1, R35.1, U1.50 (PA15)
/Encoders/EXT_ENCDB: R33.1, R36.1, U1.55 (PB3)
/Encoders/EXT_ENCDI: R34.1, R37.1, U1.29 (PB10)
/Encoders/MISO: J10.2, U1.56 (PB4), U10.3 (MISO)
/Encoders/MOSI: J10.1, U1.57 (PB5), U10.4 (MOSI)
/Encoders/SCK: J10.3, U1.21 (PA5), U10.2 (CLK)
/Gate Driver/EN_GATE: U1.40 (PC9), U2.33 (ENABLE)
/Gate Driver/FAULT: U1.30 (PB11), U2.28 (NFAULT)
/Gate Driver/GHA: R12.1, U2.8 (GHA)
/Gate Driver/GHB: R17.1, U2.17 (GHB)
/Gate Driver/GHC: R22.1, U2.18 (GHC)
/Gate Driver/GLA: R15.1, U2.10 (GLA)
/Gate Driver/GLB: R21.1, U2.15 (GLB)
/Gate Driver/GLC: R25.1, U2.20 (GLC)
/Gate Driver/IDRIVE: R7.2, R8.2, U2.30 (IDRIVE)
/Gate Driver/INH_A: U1.41 (PA8), U2.37 (INHA)
/Gate Driver/INH_B: U1.42 (PA9), U2.39 (INHB)
/Gate Driver/INH_C: U1.43 (PA10), U2.41 (INHC)
/Gate Driver/INL_A: U1.34 (PB13), U2.38 (INLA)
/Gate Driver/INL_B: U1.35 (PB14), U2.40 (INLB)
/Gate Driver/INL_C: U1.36 (PB15), U2.42 (INLC)
/Gate Driver/SHA: Q1.1 (S), Q1.2 (S), Q1.3 (S), Q2.5 (D), R13.1, U2.9 (SHA), U4.2 (+)
/Gate Driver/SHB: Q3.1 (S), Q3.2 (S), Q3.3 (S), Q4.5 (D), R19.1, U2.16 (SHB), U6.2 (+)
/Gate Driver/SHC: Q5.1 (S), Q5.2 (S), Q5.3 (S), Q6.5 (D), R23.1, U2.19 (SHC), U7.2 (+)
/Gate Driver/VDS: R10.2, R11.2, U2.31 (VDS)
/Inverter/ISENSE_A: C36.1, R14.2, TP4.1 (1_1), U1.11 (PC3)
/Inverter/ISENSE_B: C42.1, R20.2, TP6.1 (1_1), U1.17 (PA3)
/Inverter/ISENSE_C: C46.1, R24.2, TP7.1 (1_1), U1.20 (PA4)
/Inverter/OUT_A: J4.1 (Pin_1_1), R13.2, U4.3 (-)
/Inverter/OUT_B: J5.1 (Pin_1_1), R19.2, U6.3 (-)
/Inverter/OUT_C: J6.1 (Pin_1_1), R23.2, U7.3 (-)
/Inverter/PV_SENSE: TP5.1 (1_1), U1.22 (PA6), U5.3 (-), U5.4
/MCU/BOOT0: R3.2, U1.60 (BOOT0)
/MCU/LED_G: R5.1, U1.3 (PC14)
/MCU/LED_R: R4.1, U1.2 (PC13)
/MCU/NRST: C7.1, R1.2, U1.7 (NRST)
/MCU/OSC_IN: C8.2, U1.5 (PH0), Y1.1
/MCU/OSC_OUT: C9.2, U1.6 (PH1), Y1.3
/MCU/SWCLK: J1.2, U1.49 (PA14)
/MCU/SWDIO: J1.1, U1.46 (PA13)
DVDD: C20.1, R7.1, R10.1, U2.36 (DVDD)
GND: C1.2, C2.2, C3.2, C4.2, C5.2, C6.2, C7.2, C8.1, C9.1, C10.2, C11.2, C12.2, C13.2, C14.2, C16.2, C17.2, C20.2, C21.1, C22.2, C23.2, C24.2, C25.1, C26.1, C27.1, C28.1, C29.1, C30.1, C32.1, C33.1, C34.1, C35.1, C38.1, C39.1, C41.2, C43.1, C44.1, C47.1, C48.1, C49.1, C50.1, C51.2, D1.1 (K), D2.1 (K), D3.1 (K), D4.2 (A), J1.3, J2.1, J3.1, J7.A1 (GND), J7.A12 (GND), J7.B1 (GND), J7.B12 (GND), J7.S1 (SHIELD), J8.3, J9.3, J10.6, J11.5, NT1.2, Q2.1 (S), Q2.2 (S), Q2.3 (S), Q4.1 (S), Q4.2 (S), Q4.3 (S), Q6.1 (S), Q6.2 (S), Q6.3 (S), R3.1, R8.1, R9.2, R11.1, R18.2, R35.2, R36.2, R37.2, TP3.1 (1_1), U1.12 (VSSA), U1.18 (VSS), U1.63 (VSS), U2.2 (PGND), U2.11 (SPA), U2.12 (SNA), U2.13 (SNB), U2.14 (SPB), U2.21 (SPC), U2.22 (SNC), U2.27 (DGND), U2.29 (MODE), U2.35 (AGND), U2.43 (BGND), U2.49 (EP), U3.2 (GND), U8.2 (GND), U9.2 (GND), U9.8 (S), U9.9 (GND), U10.5 (TST), U10.13 (GND), Y1.2 (G), Y1.4 (G)
GNDA: C31.2, C36.2, C37.2, C40.2, C42.2, C45.2, C46.2, NT1.1, U4.1 (GND), U4.4 (GND), U4.7 (REF1), U5.2 (V-), U6.1 (GND), U6.4 (GND), U6.7 (REF1), U7.1 (GND), U7.4 (GND), U7.7 (REF1)
unnamed: C49.2, R29.1, R31.1
unnamed: D1.2 (A), R2.2
unnamed: D2.2 (A), R4.2
unnamed: D3.2 (A), R5.2
unnamed: C15.2, D4.1 (K), L1.1, U2.45 (SW)
unnamed: J7.A6 (D+), J7.B6 (D+), U8.3 (I/O2)
unnamed: J7.A7 (D-), J7.B7 (D-), U8.1 (I/O1)
unnamed: J11.1, R32.2
unnamed: J11.2, R33.2
unnamed: J11.3, R34.2
unnamed: C50.2, J11.4, JP1.2 (C)
unnamed: Q1.4 (G), R12.2
unnamed: Q2.4 (G), R15.2
unnamed: Q3.4 (G), R17.2
unnamed: Q4.4 (G), R21.2
unnamed: Q5.4 (G), R22.2
unnamed: Q6.4 (G), R25.2
unnamed: R14.1, U4.8
unnamed: R20.1, U6.8
unnamed: R24.1, U7.8
unnamed: R26.2, R28.1, U8.4 (I/O2)
unnamed: R27.1, U8.6 (I/O1)
unnamed: C10.1, U1.31 (VCAP_1)
unnamed: C11.1, U1.47 (VCAP_2)
unnamed: C15.1, U2.44 (CB)
unnamed: C19.2, U2.4 (CPH)
unnamed: C19.1, U2.3 (CPL)
unnamed: R6.2, R9.1, U2.1 (FB)
unnamed: C18.1, U2.5 (VCP)
unnamed: C24.1, U3.4 (BP)
unnamed: C41.1, R16.2, R18.1, U5.1 (+)
VS: C12.1, C13.1, C14.1, C17.1, C18.2, C25.2, C26.2, C27.2, C28.2, C29.2, C30.2, C32.2, C33.2, C34.2, C35.2, C38.2, C39.2, C43.2, C44.2, J2.2, J3.2, Q1.5 (D), Q3.5 (D), Q5.5 (D), R16.1, U2.6 (VM), U2.7 (VDRAIN), U2.47 (VIN)

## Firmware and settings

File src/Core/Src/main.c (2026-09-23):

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
/* Includes ------------------------------------------------------------------*/
#include "main.h"
#include "usb_device.h"

/* USER CODE BEGIN Includes */
#include "stm32f405_link.h"
#include "motor.h"
#include "AS5047P.h"
#include "FOC_utils.h"
#include "self_commissioning.h"
#include "storage.h"
#include "sf_motion_usb_com.h"
#include "sf_motion_com.h"
#include "string.h"
/* USER CODE END Includes */

/* USER CODE BEGIN PD */

#define usb_print(fmt, ...)                                                 \
  do {                                                                      \
    snprintf(usb_send_buff, sizeof(usb_send_buff), fmt, ##__VA_ARGS__);     \
    CDC_Transmit_FS((uint8_t *)(usb_send_buff), sizeof(usb_send_buff) - 1); \
  } while (0)

/* USER CODE END PD */

/* USER CODE BEGIN PM */
extern uint8_t CDC_Transmit_FS(uint8_t* Buf, uint16_t Len);
/* USER CODE END PM */

ADC_HandleTypeDef hadc1;

CAN_HandleTypeDef hcan1;

SPI_HandleTypeDef hspi1;
DMA_HandleTypeDef hdma_spi1_tx;
DMA_HandleTypeDef hdma_spi1_rx;

TIM_HandleTypeDef htim1;

/* USER CODE BEGIN PV */

AS5047P_t hencd1;
uint32_t adc_buff[4];
foc_t hfoc1;
self_commissioning_t hsc1;
storage_t hstorage1;

sfm_usb_com_t hsfm_usb_com;
sfm_com_t husb_com;
sfm_com_t hcan_com;

char usb_send_buff[64];
uint8_t can_send_buff[64];
uint8_t can_recv_buff[64];

/* USER CODE END PV */

void SystemClock_Config(void);
static void MX_GPIO_Init(void);
static void MX_DMA_Init(void);
static void MX_TIM1_Init(void);
static void MX_ADC1_Init(void);
static void MX_SPI1_Init(void);
static void MX_CAN1_Init(void);
/* USER CODE BEGIN 0 */

/**************************************************************************** */
// implementation

void motor1_inverter_enable(void) {
  EN_GATE1_GPIO_Port->BSRR = EN_GATE1_Pin;
  link_enable_pwm(&htim1);
  link_enable_adc(&hadc1);
}

void motor1_inverter_disable(void) {
  EN_GATE1_GPIO_Port->BSRR = EN_GATE1_Pin<<16;
  link_disable_pwm(&htim1);
  link_disable_adc(&hadc1);
}

uint32_t motor1_get_pwm_res(void) {
  return link_get_max_pwm(&htim1);
}

float motor1_as5047p_get_mech_deg(void) {
  return AS5047P_get_degree(&hencd1);
}

int motor1_as5047p_spi_transmit(uint8_t *tx, uint8_t *rx, uint16_t len) {
  if (HAL_SPI_TransmitReceive_DMA(&hspi1, tx, rx, len) == HAL_OK) return 0;
  return -1;
}

void motor1_as5047p_spi_cs(_Bool cs_state) {
  if (cs_state) SPI_CS_GPIO_Port->BSRR = SPI_CS_Pin;
  else SPI_CS_GPIO_Port->BSRR = SPI_CS_Pin<<16;
}

int write_flash(void *data, uint32_t len) {
  return link_write_flash(data, len);
}

int read_flash(void *data, uint32_t len) {
  memcpy(data, (void*)FLASH_SECTOR_ADDR, len);
  return 0;
}

int usb_send_data(uint8_t *data, uint16_t len) {
  if (CDC_Transmit_FS(data, len) != USBD_OK) return -1;
  return 0;
}

int sfm_com_usb_send_data(uint8_t *data, uint16_t len) {
  if (sfm_usb_com_start_send_data(&hsfm_usb_com, data, len) == 0) return 0;
  return -1;
}

int sfm_com_usb_recv_data(uint8_t *data, uint16_t len) {
  (void)data;
  (void)len;
  return 0;
}

int can_recv_data(uint8_t *data, uint16_t len) {
  (void)data;
  (void)len;
  return 0;
}

int can_send_data(uint8_t *data, uint16_t len) {
#if USB_TO_CAN
  return link_can_send_data(0x02, data, len);
#else
  return link_can_send_data(0x01, data, len);
#endif
}

/**************************************************************************** */

static void init_motor(void) {
  motor_init_pwm(&hfoc1.motor, &TIM1->CCR1, &TIM1->CCR2, &TIM1->CCR3);
  motor_init_adc_current_sense(&hfoc1.motor, &adc_buff[0], &adc_buff[1], &adc_buff[2]);
  motor_init_adc_power_voltage_sense(&hfoc1.motor, &adc_buff[3]);
  motor_set_current_sense_gain(&hfoc1.motor, (3.3f / 4095.0f) / (0.01f * 20.0f));
  motor_set_power_voltage_sense_gain(&hfoc1.motor, (3.3f / 4095.0f)*((39.0f + 2.2f) / 2.2f));
  motor_init_lpf_power_voltage_sense(&hfoc1.motor, 100, BLDC_PWM_FREQ);
  CSA_CAL1_GPIO_Port->BSRR = CSA_CAL1_Pin << 16;
}

static void init_encoder(void) {
  AS5047P_spi_config(&hencd1, motor1_as5047p_spi_transmit, motor1_as5047p_spi_cs);
  AS5047P_init(&hencd1, SENSOR_DIR_REVERSE, (360.0f / 16383.0f));
  AS5047P_set_angle_filter_fc(&hencd1, 1000.0f, FOC_TS);
  AS5047P_set_rpm_filter_fc(&hencd1, 50.0f, FOC_TS);
}

static void init_foc(void) {
  link_can_init();
#if USB_TO_CAN
  sfm_usb_com_init(&hsfm_usb_com, usb_send_data);
  sfm_com_init(&husb_com, sfm_com_usb_recv_data, sfm_com_usb_send_data, HAL_GetTick, &hfoc1, &hstorage1, &hsc1);
  sfm_com_init(&hcan_com, can_recv_data, can_send_data, HAL_GetTick, &hfoc1, &hstorage1, &hsc1);
#else
  init_trig_lut();
  link_set_pwm_freq(&htim1, BLDC_PWM_FREQ);
  init_motor();
  init_encoder();
  sc_init(&hsc1, &hfoc1);

  storage_init(&hstorage1, write_flash, read_flash);
  foc_inverter_init(&hfoc1, motor1_inverter_enable, motor1_inverter_disable, motor1_get_pwm_res);
  foc_feedback_sensor_init(&hfoc1, motor1_as5047p_get_mech_deg, hstorage1.memory.encoder_config.error_comp_deg, NORMAL_DIR);
  foc_speed_feedback_sensor_init(&hfoc1, 600.0f, 1.0f/SPEED_TS);

  sfm_usb_com_init(&hsfm_usb_com, usb_send_data);
  sfm_com_init(&husb_com, sfm_com_usb_recv_data, sfm_com_usb_send_data, HAL_GetTick, &hfoc1, &hstorage1, &hsc1);
  sfm_com_init(&hcan_com, can_recv_data, can_send_data, HAL_GetTick, &hfoc1, &hstorage1, &hsc1);

  storage_read_config(&hstorage1);
  storage_copy_to_local(&hstorage1, &hfoc1);

  // Id PI parameter
  pid_reset(&hfoc1.id_ctrl);
  pid_set_ts(&hfoc1.id_ctrl, FOC_TS);
  // Id PI parameter
  pid_reset(&hfoc1.iq_ctrl);
  pid_set_ts(&hfoc1.iq_ctrl, FOC_TS);
  // Speed PID parameter
  pid_reset(&hfoc1.speed_ctrl);
  pid_set_ts(&hfoc1.speed_ctrl, SPEED_TS);
  pid_set_kd(&hfoc1.speed_ctrl, 0);
  pid_set_d_filter_fc(&hfoc1.speed_ctrl, 100.0f);
  pid_set_max_d(&hfoc1.speed_ctrl, 10.0f);
  // Position PID parameter
  pid_reset(&hfoc1.pos_ctrl);
  pid_set_ts(&hfoc1.pos_ctrl, POSITION_TS);
  pid_set_d_filter_fc(&hfoc1.pos_ctrl, hfoc1.pos_ctrl.d_fc_lpf);
  pid_set_max_d(&hfoc1.pos_ctrl, 100.0f);
  // field weakening
  pid_reset(&hfoc1.fw_ctrl);
  pid_set_ts(&hfoc1.fw_ctrl, FOC_TS);

  // foc_motor_init(&hfoc1, hstorage1.memory.motor_config.pole_pairs, 360.0f);
  // foc_set_mode(&hfoc1, FOC_MODE_SENSORED);
  foc_sensorless_init(&hfoc1, BLDC_PWM_FREQ);

  foc_gear_reducer_init(&hfoc1, 1.0f);
  foc_set_limit_current(&hfoc1, 10.0f);
  
  foc_enable(&hfoc1);
#endif
}

static void indicator_update(void) {
  static uint32_t heartbeat_tick = 0;
  if (HAL_GetTick() - heartbeat_tick >= 500) {
    heartbeat_tick = HAL_GetTick();
    HAL_GPIO_TogglePin(LED_G_GPIO_Port, LED_G_Pin);
  }
  if (HAL_GPIO_ReadPin(NFAULT1_GPIO_Port, NFAULT1_Pin)) {
    LED_R_GPIO_Port->BSRR = LED_R_Pin<<16;
  }
  else {
    LED_R_GPIO_Port->BSRR = LED_R_Pin;
  }
}

static void self_commissioning_update(void) {
  if (sc_is_measure_done(&hsc1)) {
    switch(sc_get_seq(&hsc1)) {
      case SC_SEQUENCE_START_MEASURE_RS:
        foc_set_motor_Rs(&hfoc1, sc_get_Rs(&hsc1));
        break;
      case SC_SEQUENCE_START_MEASURE_LD:
        foc_set_motor_Ld(&hfoc1, sc_get_Ld(&hsc1));
        break;
      case SC_SEQUENCE_START_MEASURE_LQ:
        foc_set_motor_Lq(&hfoc1, sc_get_Lq(&hsc1));
        break;
      case SC_SEQUENCE_START_CALIBRATE_ABS_ENCODER:
        break;
    }
  }
}

void usb_to_can_update(void) {
  if (husb_com.incomming_data_flag) {
    husb_com.incomming_data_flag = 0;
    hcan_com.send_data(husb_com.data_rx, husb_com.data_rx_len);
  }
  if (hcan_com.incomming_data_flag) {
    hcan_com.incomming_data_flag = 0;
    husb_com.send_data(hcan_com.data_rx, hcan_com.data_rx_len);
  }
}

/**************************************************************************** */

void HAL_SPI_TxRxCpltCallback(SPI_HandleTypeDef *hspi) {
	if (hspi->Instance == SPI1) {
    AS5047P_set_spi_transfer_done(&hencd1);
	}
}

void HAL_ADCEx_InjectedConvCpltCallback(ADC_HandleTypeDef* hadc) {
	if (hadc->Instance == ADC1) {
    adc_buff[0] = ADC1->JDR1; // current sense A
    adc_buff[1] = ADC1->JDR2; // current sense B
    adc_buff[2] = ADC1->JDR3; // current sense C
    adc_buff[3] = ADC1->JDR4; // power voltage sense
    motor_calculate_power_voltage(&hfoc1.motor);
    motor_get_power_voltage(&hfoc1.motor, &hfoc1.v_bus);
    sc_update(&hsc1, FOC_TS);
    foc_update(&hfoc1, FOC_TS);
  }
}

// CAN RX FIFO 0 Callback
void HAL_CAN_RxFifo0MsgPendingCallback(CAN_HandleTypeDef *hcan){
  uint32_t id;
  if (link_can_recv_data(&id, hcan_com.data_rx, &hcan_com.data_rx_len) == 0) {
    hcan_com.incomming_data_flag = 1;
  }
}

/**************************************************************************** */

/* USER CODE END 0 */

/**
  * @brief  The application entry point.
  * @retval int
  */
int main(void)
{

  /* MCU Configuration--------------------------------------------------------*/

  /* Reset of all peripherals, Initializes the Flash interface and the Systick. */
  HAL_Init();

  /* Configure the system clock */
  SystemClock_Config();

  /* Initialize all configured peripherals */
  MX_GPIO_Init();
  MX_DMA_Init();
  MX_USB_DEVICE_Init();
  MX_TIM1_Init();
  MX_ADC1_Init();
  MX_SPI1_Init();
  MX_CAN1_Init();
  /* USER CODE BEGIN 2 */

#if (__FPU_PRESENT == 1) && (__FPU_USED == 1)
  printf("FPU aktif!\n");
#else
  printf("FPU tidak aktif!\n");
#endif

  init_foc();
  // uint32_t tick = HAL_GetTick();

  /* USER CODE END 2 */

  /* Infinite loop */
  /* USER CODE BEGIN WHILE */
  while (1)
  {
    indicator_update();
#if USB_TO_CAN
    usb_to_can_update();
#else
    AS5047P_update(&hencd1);
    sfm_com_update(&husb_com);
    sfm_com_update(&hcan_com);
    self_commissioning_update();
#endif
    /* USER CODE END WHILE */

    /* USER CODE BEGIN 3 */
  }
  /* USER CODE END 3 */
}

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


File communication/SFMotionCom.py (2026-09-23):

import struct
import math
import queue
import threading
import serial
import time
import json
import numpy as np
from enum import IntEnum
from pathlib import Path


class SFMComType(IntEnum):
    RESPONSE = 0x00
    READ = 0x01
    WRITE = 0x02
    ENABLE_STREAMING = 0x03
    DISABLE_STREAMING = 0x04
    STREAMING = 0x05
    EVENT = 0x06


class SFMotion:
    HEADER = b"\xA5\xA5"

    def __init__(self, serial_conn=None, acq_thread=None, json_path=None):
        self._request_lock = threading.Lock()
        self._desynchronized = False
        self.ser = serial_conn
        self.acq_thread = acq_thread

        if json_path is None:
            json_path = Path(__file__).with_name("SFMotionRegisters.json")
        with open(json_path, "r") as f:
            config = json.load(f)

        self.registers = {
            item["address"]: item
            for item in config["registers"]
        }
        self.channel = IntEnum(
            "channel",
            {
                item["name"]: item["address"]
                for item in config["registers"]
                if item["streaming"]
            }
        )
        self._create_api()

    def _create_api(self):
        for register in self.registers.values():
            address = register["address"]
            name = register["name"]
            if register["read"]:
                setattr(self, f"get_{name}", 
                    lambda address=address: self.read(address)
                )
            if register["write"]:
                setattr(self, f"set_{name}",
                    lambda value=None, address=address: self.write(address, value)
                )

    def close(self):
        self.ser.close()

    def set_foc_motor_mode(self, mode):
        """Keep the legacy console command compatible with the motor_mode register."""
        return self.set_motor_mode(mode)

    # ------------------------------------------------------------
    # Low-level communication
    # ------------------------------------------------------------

    def _send_frame(self, com_type, address, data=b""):
        payload = bytes([com_type, address]) + data
        frame = (self.HEADER + bytes([len(payload)]) + payload)
        # print(f"TX: {frame.hex(' ')}")
        self.ser.write(frame)

    def validate_write(self, address, value):
        register = self.registers.get(address)
        if register is None or not register["write"]:
            raise ValueError(f"Address {address} is not writable")
        name = register["name"]
        if name.startswith(("id_", "iq_", "speed_", "position_", "fw_")) and name.endswith(
            ("_kp", "_ki", "_kd", "_deadband", "_out_max", "_out_min", "_d_filter_fc")
        ):
            valid = math.isfinite(value)
            if name.endswith("_out_min"):
                valid = valid and value <= 0
            elif name.endswith("_d_filter_fc"):
                valid = valid and value > 0
            else:
                valid = valid and value >= 0
            if not valid:
                raise ValueError(f"Invalid PID value for {name}: {value}")
        if register["format"] is not None:
            struct.pack(register["format"], value)

    def _exchange(self, com_type, address, data=b"", expected_size=1):
        # Only one outstanding request: the wire protocol has no transaction ID.
        with self._request_lock:
            disable = (com_type == SFMComType.WRITE and
                       self.registers[address]["name"] == "motor_mode" and data == b"\x06")
            if self._desynchronized:
                if disable:
                    self._send_frame(com_type, address, data)
                    raise RuntimeError("Disable sent but unconfirmed; reconnect before further requests")
                raise RuntimeError("Communication is unsynchronized; reconnect before further requests")
            try:
                self._send_frame(com_type, address, data)
                response_address, response = self.acq_thread.response_queue.get(timeout=2)
                if response_address != address or len(response) != expected_size:
                    raise RuntimeError("Unexpected response; reconnect before further requests")
            except Exception as exc:
                self._desynchronized = True
                if isinstance(exc, queue.Empty):
                    raise TimeoutError("Response timed out; reconnect before further requests") from exc
                raise
            return response

    def read(self, address):
        register = self.registers.get(address)
        if register is None or not register["read"] or register["format"] is None:
            raise ValueError(f"Address {address} is not readable")
        fmt = register["format"]
        data = self._exchange(SFMComType.READ, address, expected_size=struct.calcsize(fmt))
        return struct.unpack(fmt, data)[0]

    def write(self, address, value=None):
        self.validate_write(address, value)
        fmt = self.registers[address]["format"]
        data = b"" if fmt is None else struct.pack(fmt, value)
        self._check_status(self._exchange(SFMComType.WRITE, address, data))
        return True

    @staticmethod
    def _check_status(response):
        status = struct.unpack("<b", response)[0]
        if status != 0:
            raise RuntimeError(f"Device returned error: {status}")

    def enable_streaming(self, address):
        self._check_status(self._exchange(SFMComType.ENABLE_STREAMING, address))

    def disable_streaming(self, address):
        self._check_status(self._exchange(SFMComType.DISABLE_STREAMING, address))

    # ----------------------------------------------------------------------------------

    def self_commissioning(self):
        self.set_start_measure_resistance()
        time.sleep(1)
        self.set_start_measure_ld()
        time.sleep(1)
        self.set_start_measure_lq()
        time.sleep(1)
        self.get_motor_param()
        self.set_foc_bandwidth(500)
        self.set_start_calibrate_abs_encoder()

    def get_motor_param(self):
        pole_pairs = self.get_pole_pairs()
        rs = self.get_rs()
        ld = self.get_ld()
        lq = self.get_lq()
        print(f'pole pairs:{pole_pairs}')
        print(f'Rs:{rs}')
        print(f'Ld:{ld}')
        print(f'Lq:{lq}')

    def set_foc_bandwidth(self,bw=100):
        rs = self.get_rs() / 2
        ld = self.get_ld() / 2
        lq = self.get_lq() / 2
        omega = 2 * np.pi * bw
        id_kp = ld * omega
        id_ki = rs * omega
        iq_kp = lq * omega
        iq_ki = rs * omega
        print(f'id: kp={id_kp} ki={id_ki}')
        print(f'iq: kp={iq_kp} ki={iq_ki}')
        self.set_id_kp(id_kp)
        self.set_id_ki(id_ki)
        self.set_id_deadband(0)
        self.set_iq_kp(iq_kp)
        self.set_iq_ki(iq_ki)
        self.set_iq_deadband(0)

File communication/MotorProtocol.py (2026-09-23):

from SFMotionCom import SFMotion


class MotorProtocol:
    """Compatibility API for the custom plotter using the current SFM protocol."""

    _channel_registers = {
        "ia": "ia",
        "ib": "ib",
        "ic": "ic",
        "i_alpha": "i_alpha",
        "i_beta": "i_beta",
        "id": "id",
        "iq": "iq",
        "va": "va",
        "vb": "vb",
        "vc": "vc",
        "v_alpha": "v_alpha",
        "v_beta": "v_beta",
        "vd": "vd",
        "vq": "vq",
        "e_rad": "e_rad",
        "actual_rpm": "actual_rpm",
        "actual_angle": "actual_angle",
        "Is_ref": "is_ref",
        "rpm_ref": "rpm_ref",
        "pos_ref": "pos_ref",
        "m_angle_rad": "m_angle_rad",
        "m_angle_rad_comp": "m_angle_rad_comp",
        "v_bus": "v_bus",
    }

    def __init__(self, serial_conn=None, acq_thread=None, config_file=None):
        self.protocol = SFMotion(serial_conn, acq_thread)
        self.ser = serial_conn
        self.acq_thread = acq_thread
        self.plotter_channels = []
        register_addresses = {
            register["name"]: address
            for address, register in self.protocol.registers.items()
        }
        self.plotter_dict = {
            name: register_addresses[register_name]
            for name, register_name in self._channel_registers.items()
        }
        self._address_to_channel = {address: name for name, address in self.plotter_dict.items()}

    def _get_value(self, name):
        return getattr(self.protocol, f"get_{name}")()

    def _set_value(self, name, value):
        return getattr(self.protocol, f"set_{name}")(value)

    def _get_group(self, names):
        return {key: self._get_value(register) for key, register in names.items()}

    def _set_group(self, names, values):
        addresses = {r["name"]: addr for addr, r in self.protocol.registers.items()}
        for key, register in names.items():
            self.protocol.validate_write(addresses[register], values[key])
        try:
            for key, register in names.items():
                self._set_value(register, values[key])
        except Exception as exc:
            raise RuntimeError(
                "Parameter group may be partially applied. Reconnect if required, "
                "then read all parameters before retrying."
            ) from exc
        return True

    def get_actual_angle(self):
        return self._get_value("actual_angle")

    def get_foc_mode(self):
        return {"mode": self._get_value("foc_mode")}

    def set_foc_mode(self, mode):
        return self._set_value("foc_mode", mode)

    def get_foc_motor_mode(self):
        return {"mode": self._get_value("motor_mode")}

    def set_foc_motor_mode(self, mode):
        return self._set_value("motor_mode", mode)

    def set_foc_current_set_point(self, value):
        return self._set_value("current_set_point", value)

    def set_foc_speed_set_point(self, value):
        return self._set_value("speed_set_point", value)

    def set_foc_position_set_point(self, value):
        return self._set_value("position_set_point", value)

    def set_pole_pairs(self, value):
        return self._set_value("pole_pairs", value)

    def get_pole_pairs(self):
        return {"value": self._get_value("pole_pairs")}

    def get_pid_id(self):
        return self._get_group({"kp": "id_kp", "ki": "id_ki", "deadband": "id_deadband"})

    def set_pid_id(self, kp, ki, deadband):
        return self._set_group({"kp": "id_kp", "ki": "id_ki", "deadband": "id_deadband"},
                               {"kp": kp, "ki": ki, "deadband": deadband})

    def get_pid_iq(self):
        return self._get_group({"kp": "iq_kp", "ki": "iq_ki", "deadband": "iq_deadband"})

    def set_pid_iq(self, kp, ki, deadband):
        return self._set_group({"kp": "iq_kp", "ki": "iq_ki", "deadband": "iq_deadband"},
                               {"kp": kp, "ki": ki, "deadband": deadband})

    def get_pid_speed(self):
        return self._get_group({"kp": "speed_kp", "ki": "speed_ki", "out_max": "speed_out_max",
                                "deadband": "speed_deadband"})

    def set_pid_speed(self, kp, ki, out_max, deadband):
        return self._set_group(
            {"kp": "speed_kp", "ki": "speed_ki", "out_max": "speed_out_max",
             "deadband": "speed_deadband"},
            {"kp": kp, "ki": ki, "out_max": out_max, "deadband": deadband},
        )

    def get_pid_position(self):
        return self._get_group({"kp": "position_kp", "ki": "position_ki", "kd": "position_kd",
                                "out_max": "position_out_max", "deadband": "position_deadband",
                                "d_fc": "position_d_filter_fc"})

    def set_pid_position(self, kp, ki, kd, out_max, deadband, d_fc):
        return self._set_group(
            {"kp": "position_kp", "ki": "position_ki", "kd": "position_kd",
             "out_max": "position_out_max", "deadband": "position_deadband",
             "d_fc": "position_d_filter_fc"},
            {"kp": kp, "ki": ki, "kd": kd, "out_max": out_max,
             "deadband": deadband, "d_fc": d_fc},
        )

    def get_field_weakening(self):
        return self._get_group({"kp": "fw_kp", "ki": "fw_ki", "out_min": "fw_out_min"})

    def set_field_weakening(self, kp, ki, out_min):
        return self._set_group({"kp": "fw_kp", "ki": "fw_ki", "out_min": "fw_out_min"},
                               {"kp": kp, "ki": ki, "out_min": out_min})

    def get_field_weakening_enable(self):
        return {"enable": self._get_value("fw_enable")}

    def set_field_weakening_enable(self, enable):
        return self._set_value("fw_enable", int(bool(enable)))

    def get_mtpa_enable(self):
        return {"enable": self._get_value("mtpa_enable")}

    def set_mtpa_enable(self, enable):
        return self._set_value("mtpa_enable", int(bool(enable)))

    def plotter_add_line(self, channel):
        if channel not in self.plotter_dict:
            raise ValueError(f"Unknown plot channel: {channel}")
        if channel not in self.plotter_channels:
            self.protocol.enable_streaming(self.plotter_dict[channel])
            self.plotter_channels.append(channel)
        return True

    def plotter_remove_line(self, channel):
        if channel in self.plotter_channels:
            self.protocol.disable_streaming(self.plotter_dict[channel])
            self.plotter_channels.remove(channel)
        return True

    def plotter_remove_all_line(self):
        for channel in list(self.plotter_channels):
            self.plotter_remove_line(channel)
        return True
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

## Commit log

2026-09-20 Update hardware exports and motor firmware
    [Inverter.kicad_sch, bom_with link.xlsx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]
2026-09-20 Recover custom Python GUI
    [motor_commands.json]
2026-10-19 Adapt GUI console and regression tests to device-ID protocol

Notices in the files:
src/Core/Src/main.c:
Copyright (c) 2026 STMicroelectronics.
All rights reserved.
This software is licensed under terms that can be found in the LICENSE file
